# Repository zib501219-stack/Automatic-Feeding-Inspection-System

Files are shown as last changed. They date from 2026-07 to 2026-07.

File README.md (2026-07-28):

# 阶梯轴自动上料与检测设备

本目录为按简历项目重新建立的可编辑机械设计包。关键自制件采用 SolidWorks 原生草图、拉伸、凸台等特征建模；外购电机、减速机、气缸和振动盘为接口级简化件，并在 BOM 中单独标明。

## 简历基线

- 阶梯轴长度 60 mm、最大直径 20 mm
- 振动盘加直线轨道
- V 形块定位
- 气源压力 0.5 MPa

## 工程补全说明

- 阶梯轴按总长 60 mm、最大直径 20 mm 建模；其余台阶尺寸为工艺布置用设计值。
- 气缸按 0.5 MPa 气源选型核算，安装孔和行程为本次设计值。
- 振动盘只保留安装、料斗和出料接口，不宣称具备真实振动整列性能。

## 目录

- `SolidWorks/parts`：原生零件源文件，保留特征树。
- `SolidWorks/assemblies`：功能子装配与总装源文件。
- `STEP`：零件、子装配和总装交换格式。
- `Drawings`：关键零件与总装的 SolidWorks 工程图、PDF、DXF。
- `Screenshots`：零件、子装配和总装等轴测截图。
- `Documents`：参数、BOM、计算说明和制造说明。
- `Validation`：生成记录与打开验证记录。

## 装配状态

- 功能子装配内的零件按已复核设计姿态固定，避免再次拖动造成关节错位。
- 总装以基座/机架模块为固定基准，其余模块通过前视、上视、右视三组基准面配合定位。
- `Validation/assembly_correctness_report.json` 记录零件变换、模块配合和关节/支撑链闭合检查。
- `Validation/assembly_views` 提供正视、右视和等轴测复核图。

## 证据边界

这是数字化结构设计和可打开性验证，不等同于实机制造、装配、节拍、精度或负载试验。文件中不会把外购简化件、估算计算或软件打开检查写成实机结果。

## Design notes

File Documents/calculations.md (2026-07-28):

# 设计计算摘要

## 气缸推力

气源压力按 0.5 MPa。分料气缸采用 20 mm 缸径时，理论推力约为 `0.5×π×20²/4 = 157 N`；按 0.8 综合效率，可用推力约 126 N。推料气缸采用 25 mm 缸径时，理论推力约 245 N，可用推力约 196 N。

## 工件与定位

阶梯轴总长 60 mm、最大直径 20 mm。V 形定位块留有侧向调整槽，检测支架留有高度调整槽；这些尺寸用于覆盖不同台阶位置和传感器工作距离。

计算只证明方案级选型有余量，不等同于振动盘节拍、卡料率、检测精度或气缸寿命实测。

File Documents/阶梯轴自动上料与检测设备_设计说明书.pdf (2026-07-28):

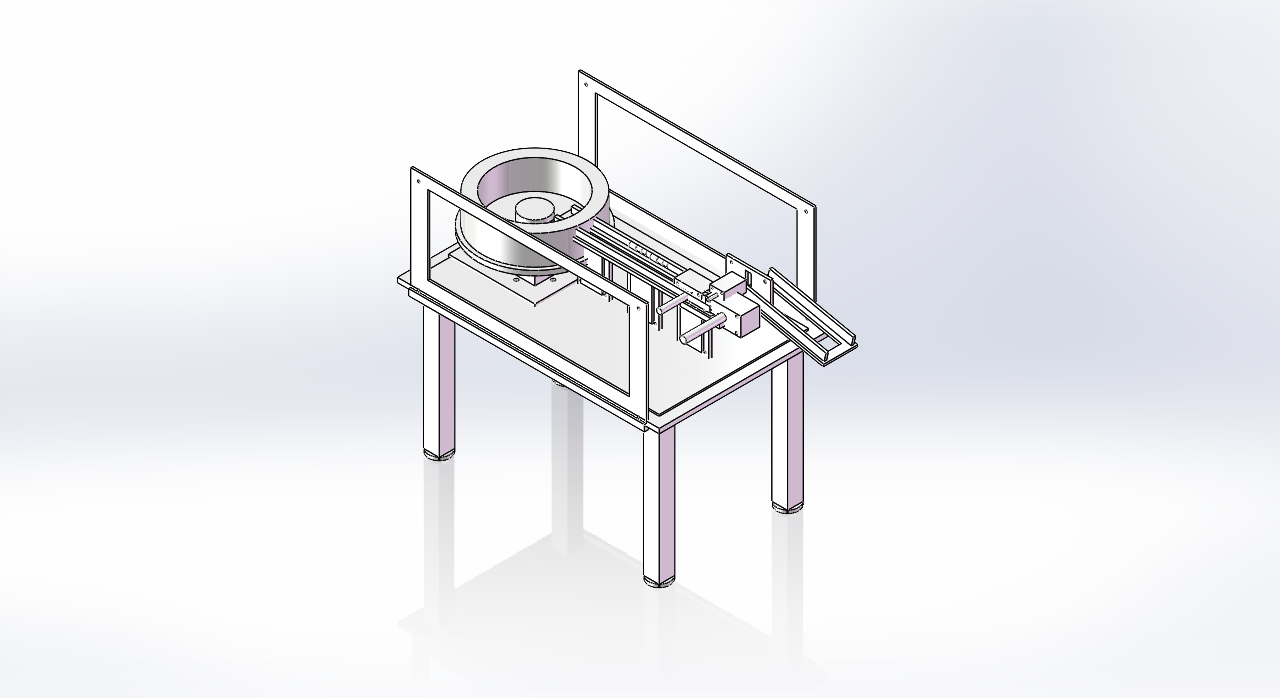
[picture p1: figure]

机械结构设计数字化交付包 | 第 1 页

# 阶梯轴自动上料与检测设备

### 机械结构设计数字化说明书

项目周期 | 2025.10—2026.01
设计软件 | SOLIDWORKS 2023
文件状态 | 原生零件、子装配、总装、STEP、工程图均已生成

说明：本书记录数字化结构设计、工程假设和软件打开检查，不把设计目标、估算或软件仿真写成实机测量结果。

机械结构设计数字化交付包 | 第 2 页

## 1 设计任务与简历基线

本项目按简历中的名称、负载、工作范围、工件规格和功能链重新建立，明确数据直接作为设计输入， 缺失接口尺寸用可追溯工程假设补全。

— 工件长度 60 mm、最大直径 20 mm

— 振动盘与直线轨道

— V 形块定位

— 气源压力 0.5 MPa

### 设计原则

— 关键自制件采用原生草图和特征树，不用导入体冒充源文件。

— 外购电机、减速机、气缸、传感器或振动盘只建接口级简化件。

— 总装按功能模块拆分，保留零件号、子装配和总装层级。

— 制造、装配、实机节拍与负载结果保持边界，不做未验证承诺。

机械结构设计数字化交付包 | 第 3 页

## 2 总体结构方案

### 功能分解

— 机架与台面

— 振动盘与直线送料

— 单件分离与 V 形定位

— 检测、推料与分选防护

总装采用统一项目坐标：SolidWorks 上视基准面建立水平安装面，Y 轴为装配竖直方向。零件定位参数由底座/台面基准逐级展开，功能子装配再插入总装。

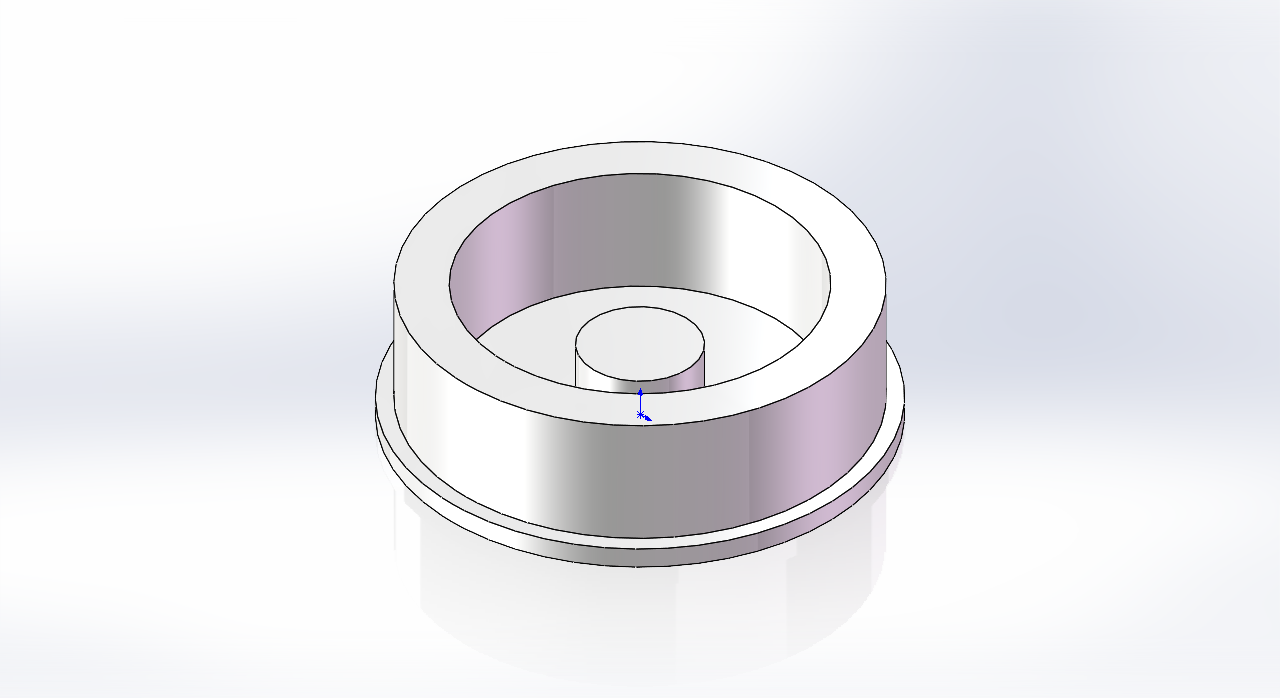
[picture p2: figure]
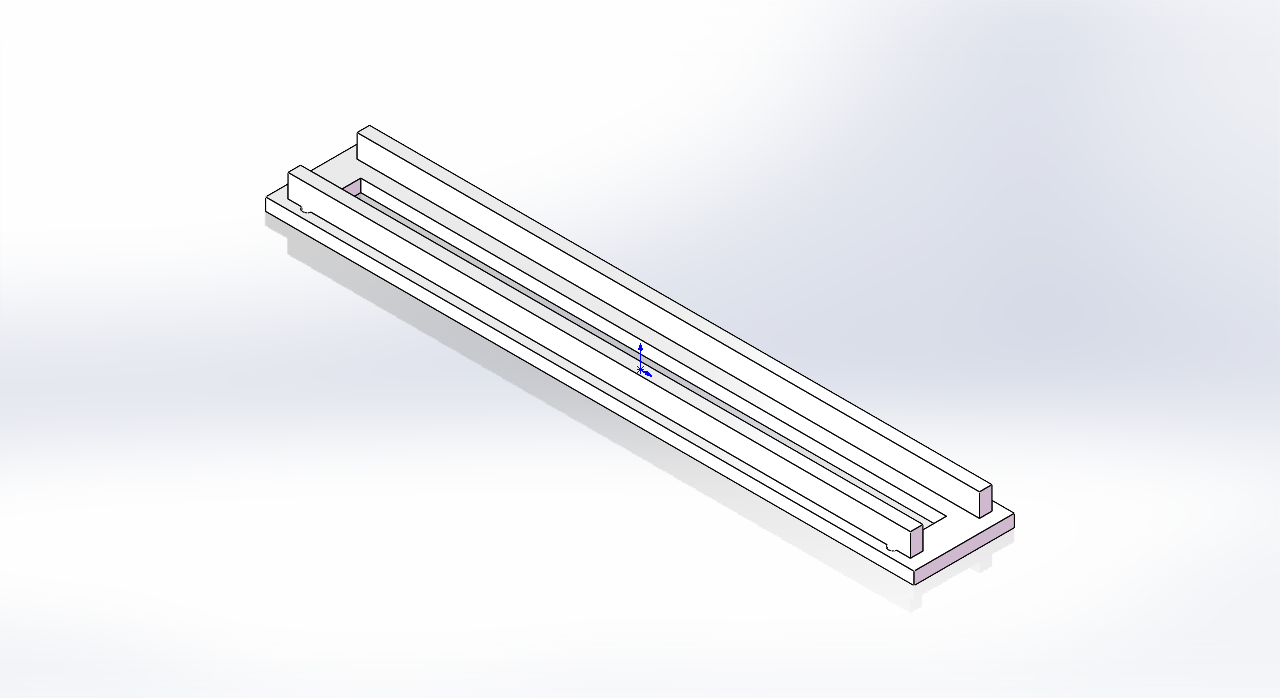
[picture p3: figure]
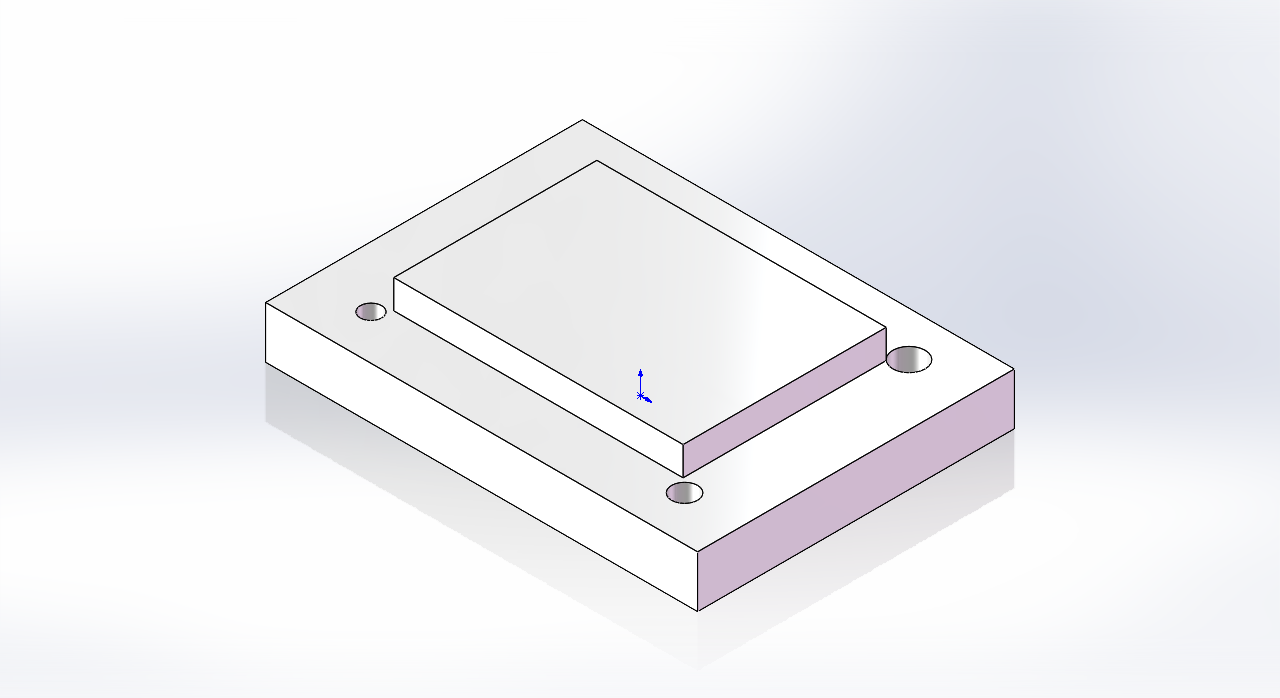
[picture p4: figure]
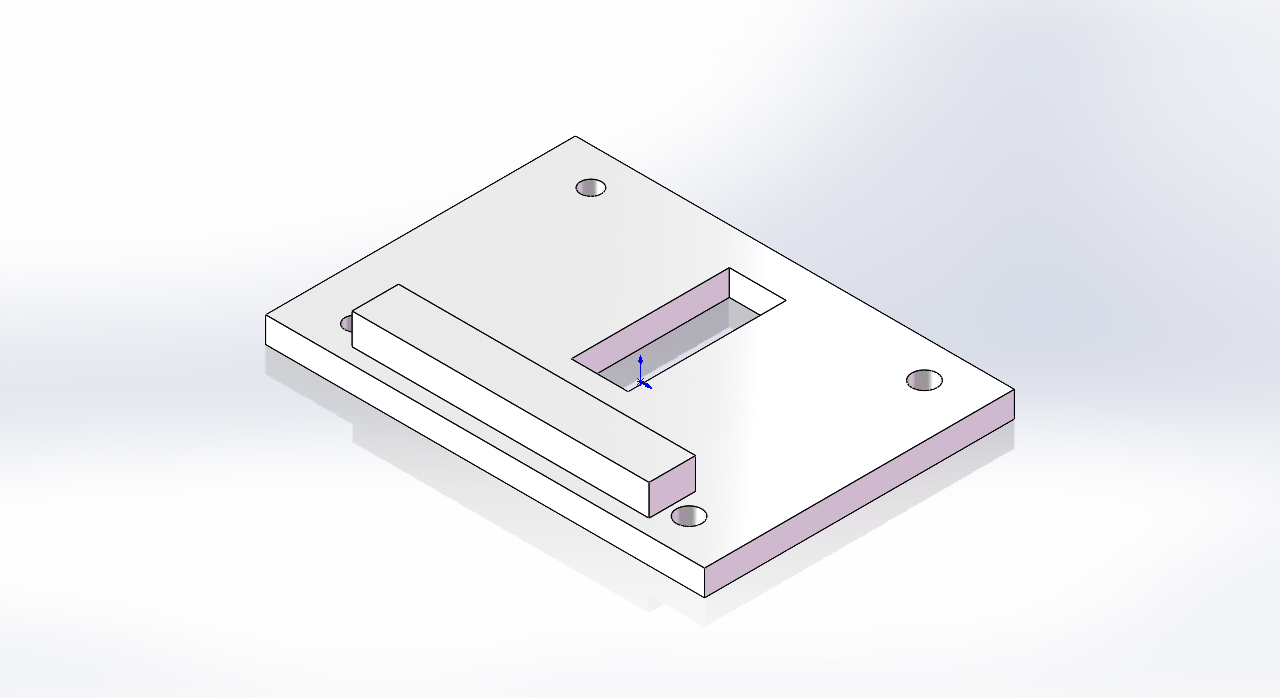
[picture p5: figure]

机械结构设计数字化交付包 | 第 4 页

## 3 关键零件设计

下列零件均保留 SolidWorks 原生特征。板件包含安装孔、调整槽、轴承/定位凸台或加强筋；轴和法兰 采用多级台阶、止口和螺栓圆；外购件以接口包络表达。

机械结构设计数字化交付包 | 第 5 页

## 4 BOM 与零件层级

本项目包含 17 种零件。自制件与外购简化件在 BOM 中分开标识，重复件按实际装配数量统计。

图号 | 名称 | 数量 | 材料/类型 | 建模来源
FD-001 | 设备台面 | 1 | Q235B | 自制件原生建模
FD-002 | 机架立柱 | 4 | Q235B | 自制件原生建模
FD-003 | 振动盘安装板 | 1 | Q235B | 自制件原生建模
FD-004 | 振动盘料斗简化件 | 1 | SUS304 | 外购简化
FD-005 | 振动盘驱动器简化件 | 1 | 外购件 | 外购简化
FD-006 | 直线送料轨道 | 1 | 6061-T6 | 自制件原生建模
FD-007 | 轨道高度调节板 | 3 | Q235B | 自制件原生建模
FD-008 | 单件分离挡块 | 1 | 45钢 | 自制件原生建模
FD-009 | 分料气缸简化件 | 1 | 外购件 | 外购简化
FD-010 | V形定位座底板 | 1 | Q235B | 自制件原生建模
FD-011 | V形定位块 | 2 | 45钢 | 自制件原生建模
FD-012 | 检测传感器支架 | 1 | Q235B | 自制件原生建模
FD-013 | 位移传感器简化件 | 1 | 外购件 | 外购简化
FD-014 | 推料气缸简化件 | 1 | 外购件 | 外购简化
FD-015 | 分选滑槽 | 1 | Q235B | 自制件原生建模
FD-016 | 透明防护罩框架 | 2 | 6061-T6 | 自制件原生建模
FD-017 | 被检测阶梯轴（60×20） | 5 | 45钢 | 自制件原生建模

机械结构设计数字化交付包 | 第 6 页

## 5 选型与校核摘要

— 分料气缸按 20 mm 缸径、0.5 MPa 计算，理论推力约 157 N。

— 按 0.8 综合效率，可用推力约 126 N。

— 推料气缸按 25 mm 缸径计算，理论推力约 245 N，可用推力约 196 N。

— V 形块和检测支架均设置可调安装槽，用于覆盖台阶位置与传感器工作距离。

### 计算边界

上述数值用于结构尺寸和驱动初选。它们没有覆盖真实加减速曲线、摩擦离散、装配误差、温升、寿命 和控制响应，因此不得替代实机试验或厂家选型复核。

机械结构设计数字化交付包 | 第 7 页

## 6 制造与装配考虑

— 板类件优先切割下料，定位孔、轴承孔和止口在基准确定后精加工。

— 轴类件采用车削和台阶精加工；正式出图前补齐配合公差、表面粗糙度和热处理要求。

— 装配按底座/机架、功能臂段/送料模块、末端/检测模块顺序进行，先定位再紧固。

— 所有外购简化件在采购前必须用真实厂家二维图或 STEP 复核孔距、轴径和外形包络。

— 为维护和拆装保留了侧板螺栓空间、调整槽以及模块分界。

### 工程图输出

关键零件和总装均输出 SLDDRW、PDF 和 DXF。PDF 用于浏览，DXF 用于二维交换，正式加工仍应以经审核、补齐公差与技术要求后的版本为准。

机械结构设计数字化交付包 | 第 8 页

## 7 文件与验证记录

项目 | 数量/说明
原生零件 | 17
功能子装配 | 3
总装 | 1
工程图 | 12
交换格式 | STEP / PDF / DXF

— 生成阶段检查原生文件、STEP 和截图均非空。

— 总装 STEP 已进行几何事实、主平面和定位信息检查。

— 总装 STEP 已生成独立 CAD 快照并人工复核结构姿态。

— 交付前还会逐个重开 SLDPRT、SLDASM、SLDDRW、STEP 和 PDF。

— 实机制造、装配、节拍、精度和负载验证不在本次数字化交付范围内。

结论

该设计包能够支撑作品展示、简历项目讲解和后续继续修改。它有清晰的零件号、功能模块、参数来源 和验证边界，可继续补充真实供应商型号、公差、工艺与实机记录。

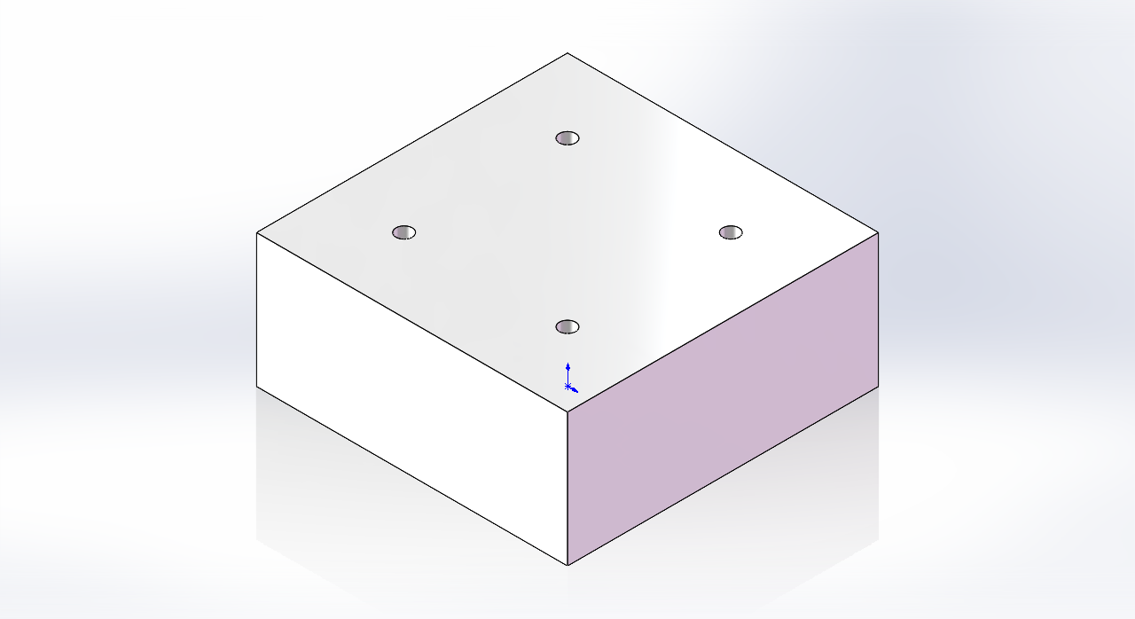
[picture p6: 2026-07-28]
Screenshots/FD-005_bowl_drive.png

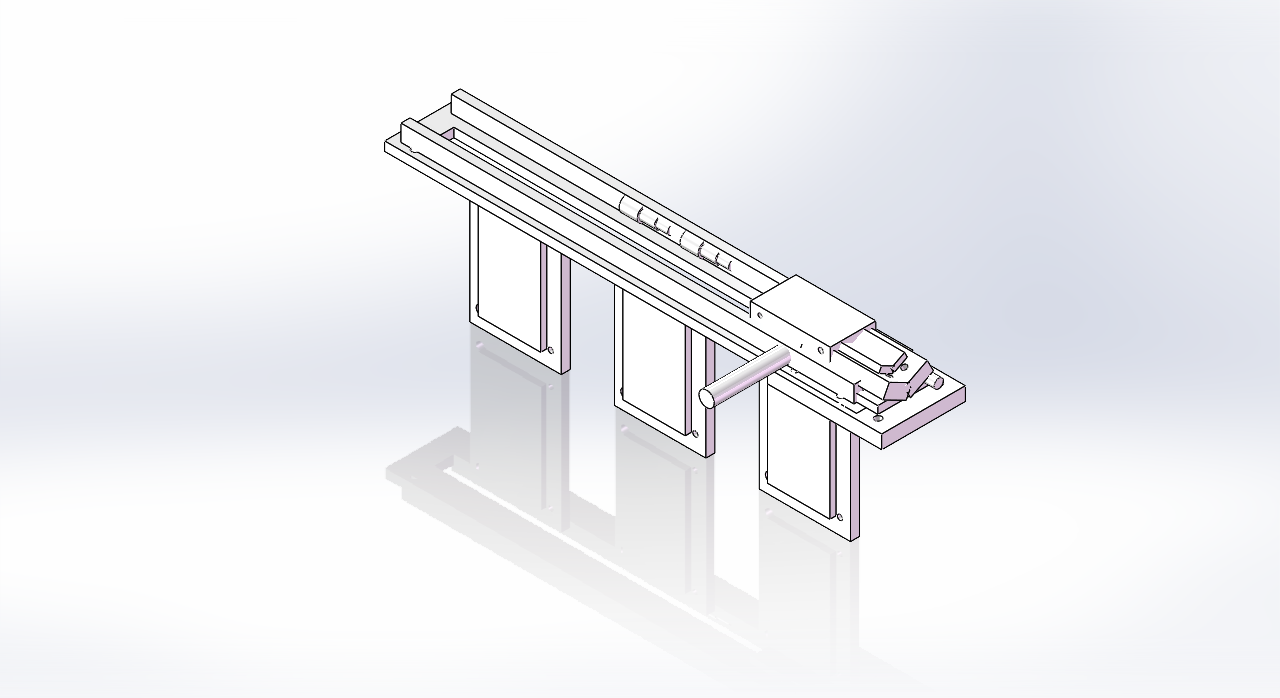
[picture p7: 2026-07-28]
Screenshots/FD-200_feed_position_module.png

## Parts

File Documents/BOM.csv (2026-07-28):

图号 | 名称 | 数量 | 材料/类型 | 建模来源 | 零件文件 | STEP文件
FD-001 | 设备台面 | 1 | Q235B | 自制件原生建模 | FD-001_machine_table.SLDPRT | FD-001_machine_table.STEP
FD-002 | 机架立柱 | 4 | Q235B | 自制件原生建模 | FD-002_frame_leg.SLDPRT | FD-002_frame_leg.STEP
FD-003 | 振动盘安装板 | 1 | Q235B | 自制件原生建模 | FD-003_bowl_base.SLDPRT | FD-003_bowl_base.STEP
FD-004 | 振动盘料斗简化件 | 1 | SUS304 | 外购简化 | FD-004_vibratory_bowl.SLDPRT | FD-004_vibratory_bowl.STEP
FD-005 | 振动盘驱动器简化件 | 1 | 外购件 | 外购简化 | FD-005_bowl_drive.SLDPRT | FD-005_bowl_drive.STEP
FD-006 | 直线送料轨道 | 1 | 6061-T6 | 自制件原生建模 | FD-006_linear_track.SLDPRT | FD-006_linear_track.STEP
FD-007 | 轨道高度调节板 | 3 | Q235B | 自制件原生建模 | FD-007_track_support.SLDPRT | FD-007_track_support.STEP
FD-008 | 单件分离挡块 | 1 | 45钢 | 自制件原生建模 | FD-008_separator_block.SLDPRT | FD-008_separator_block.STEP
FD-009 | 分料气缸简化件 | 1 | 外购件 | 外购简化 | FD-009_separator_cylinder.SLDPRT | FD-009_separator_cylinder.STEP
FD-010 | V形定位座底板 | 1 | Q235B | 自制件原生建模 | FD-010_vblock_base.SLDPRT | FD-010_vblock_base.STEP
FD-011 | V形定位块 | 2 | 45钢 | 自制件原生建模 | FD-011_vblock_jaw.SLDPRT | FD-011_vblock_jaw.STEP
FD-012 | 检测传感器支架 | 1 | Q235B | 自制件原生建模 | FD-012_sensor_bracket.SLDPRT | FD-012_sensor_bracket.STEP
FD-013 | 位移传感器简化件 | 1 | 外购件 | 外购简化 | FD-013_sensor_body.SLDPRT | FD-013_sensor_body.STEP
FD-014 | 推料气缸简化件 | 1 | 外购件 | 外购简化 | FD-014_pusher_cylinder.SLDPRT | FD-014_pusher_cylinder.STEP
FD-015 | 分选滑槽 | 1 | Q235B | 自制件原生建模 | FD-015_diverter_chute.SLDPRT | FD-015_diverter_chute.STEP
FD-016 | 透明防护罩框架 | 2 | 6061-T6 | 自制件原生建模 | FD-016_guard_panel.SLDPRT | FD-016_guard_panel.STEP
FD-017 | 被检测阶梯轴（60×20） | 5 | 45钢 | 自制件原生建模 | FD-017_workpiece_shaft.SLDPRT | FD-017_workpiece_shaft.STEP

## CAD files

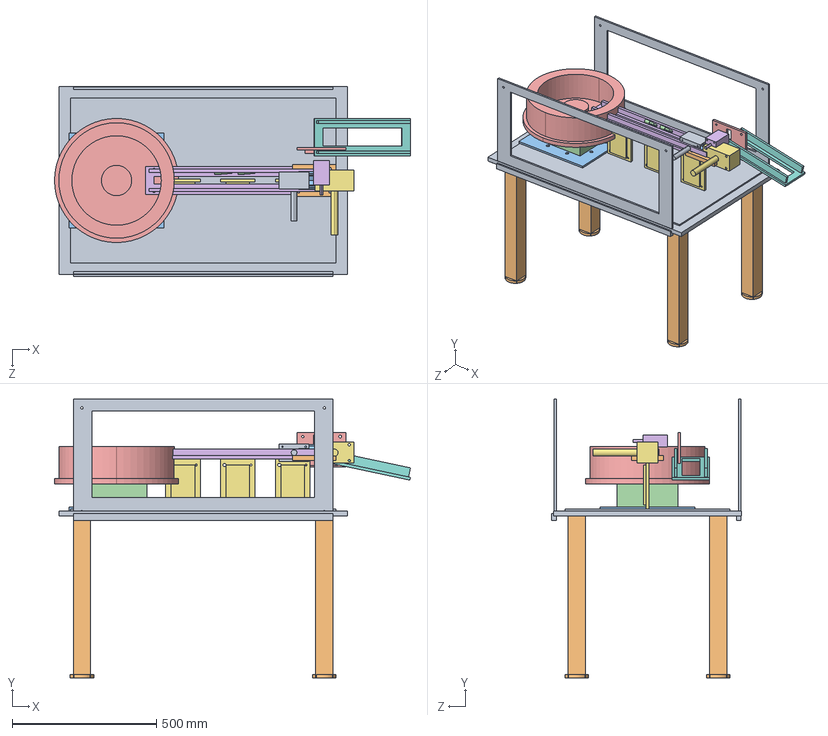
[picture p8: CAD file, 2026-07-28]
STEP/assemblies/FD-000_main_assembly.STEP
1233.4 x 965.0 x 657.0 mm
FD-001_machine_table
FD-002_frame_leg x 4
FD-003_bowl_base
FD-005_bowl_drive
FD-004_vibratory_bowl
FD-006_linear_track
FD-007_track_support x 3
FD-008_separator_block
FD-009_separator_cylinder
FD-010_vblock_base
FD-011_vblock_jaw x 2
FD-017_workpiece_shaft x 3
FD-012_sensor_bracket
FD-013_sensor_body
FD-014_pusher_cylinder
FD-015_diverter_chute
FD-016_guard_panel x 2

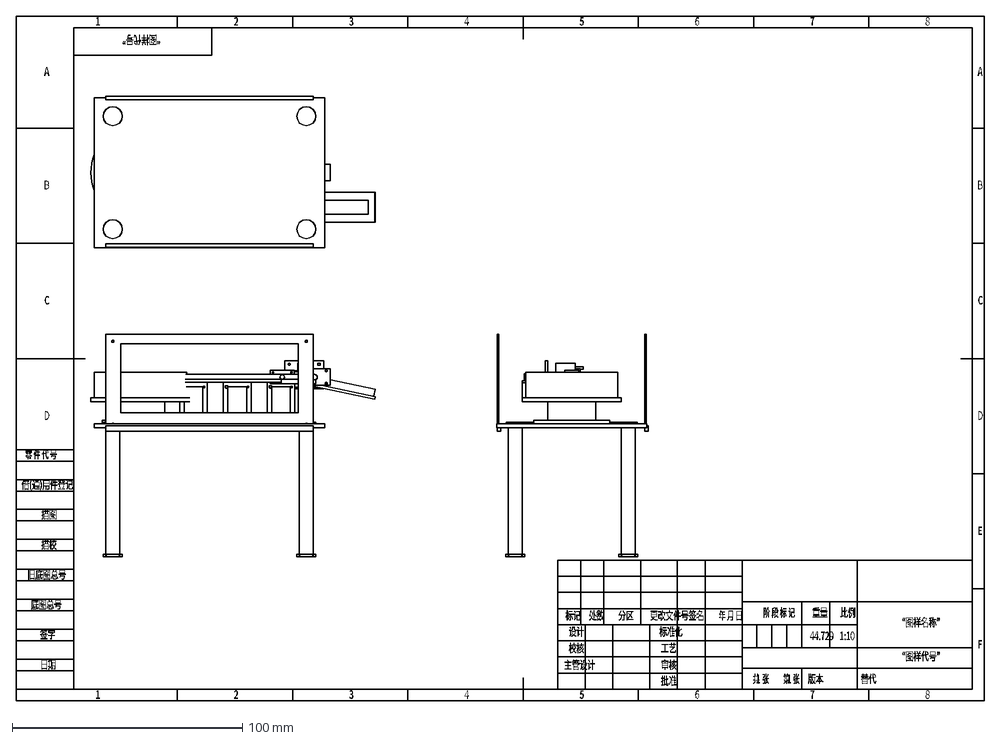
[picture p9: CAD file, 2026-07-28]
Drawings/FD-000_main_assembly.DXF
审核
校核
设计
标记
处数
分区
更改文件号
签名
年 月 日
工艺
标准化
批准
阶 段 标 记
共 张
第 张
重量
比例
日期
签字
底图总号
旧底图总号
描校
描图
借(通)用件登记
零 件 代 号
版本
主管设计
替代
“图样代号”
1:10
1
44.729
“图样名称”
2
7
6
5
4
3
8
F
E
D
C
B
A

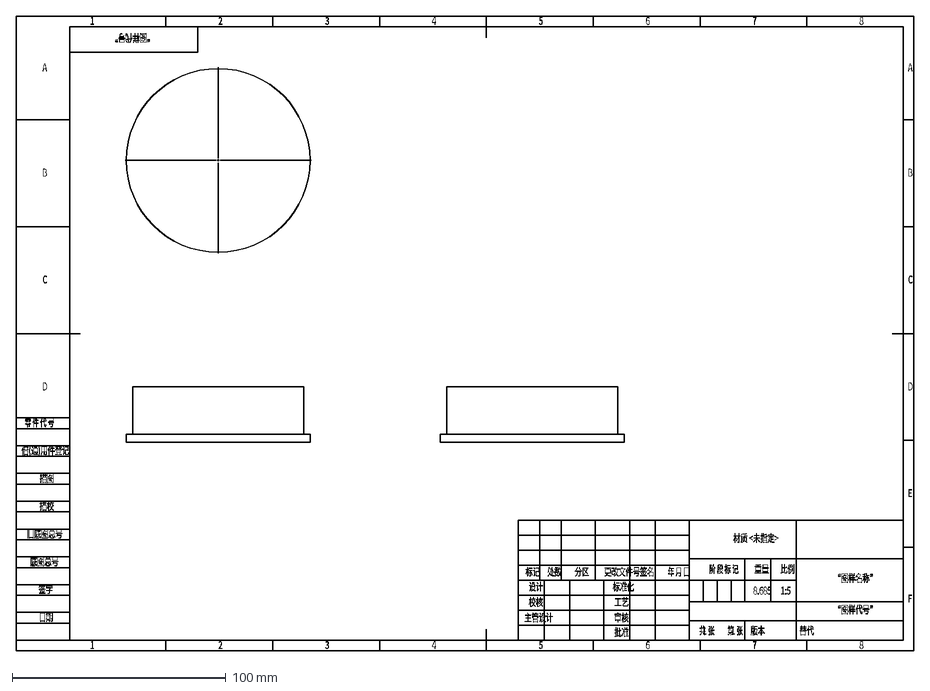
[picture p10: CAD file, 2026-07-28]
Drawings/FD-004_vibratory_bowl.DXF
审核
校核
设计
标记
处数
分区
更改文件号
签名
年 月 日
工艺
标准化
批准
阶 段 标 记
共 张
第 张
重量
比例
日期
签字
底图总号
旧底图总号
描校
描图
借(通)用件登记
零 件 代 号
版本
主管设计
替代
“图样代号”
1:5
1
8.685
“图样名称”
材质 <未指定>
2
7
6
5
4
3
8
F
E
D
C
B
A

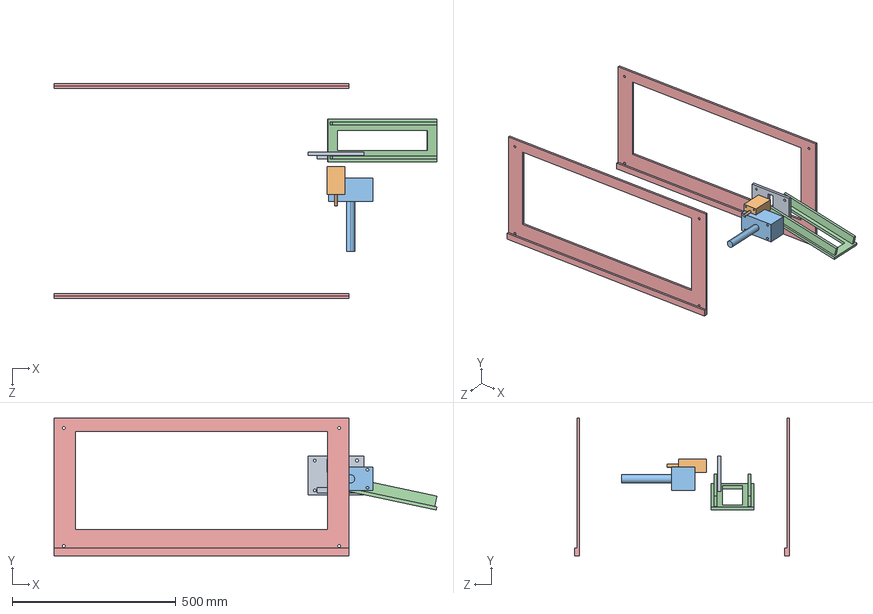
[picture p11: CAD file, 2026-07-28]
STEP/assemblies/FD-300_inspection_divert_module.STEP
1168.4 x 420.0 x 656.0 mm
FD-012_sensor_bracket
FD-013_sensor_body
FD-014_pusher_cylinder
FD-015_diverter_chute
FD-016_guard_panel x 2

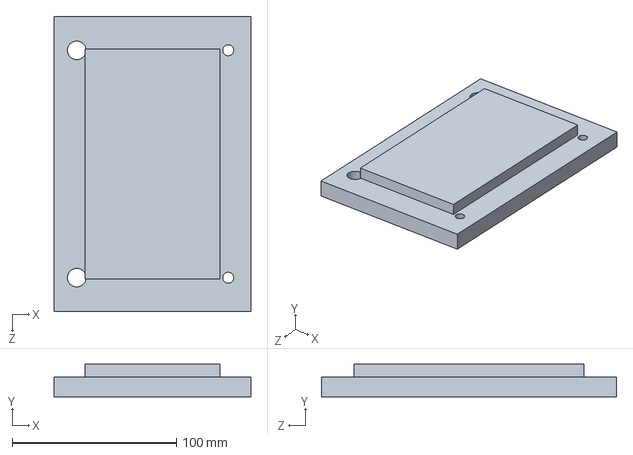
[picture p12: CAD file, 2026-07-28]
STEP/parts/FD-007_track_support.STEP
120.0 x 20.0 x 180.0 mm

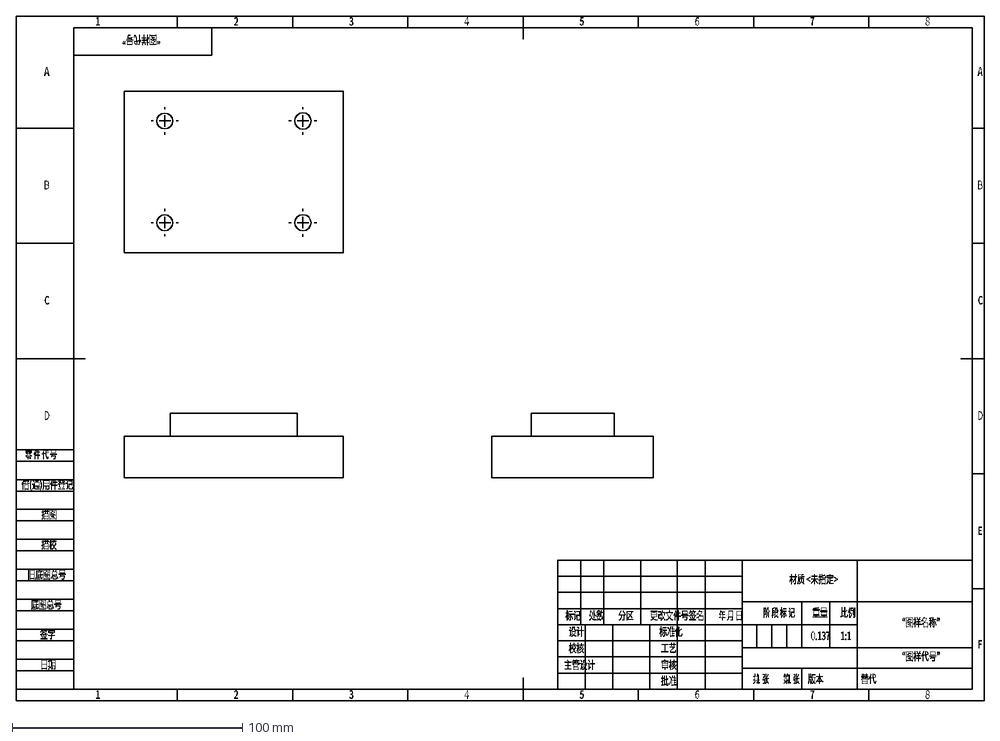
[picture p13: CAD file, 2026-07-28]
Drawings/FD-008_separator_block.DXF
审核
校核
设计
标记
处数
分区
更改文件号
签名
年 月 日
工艺
标准化
批准
阶 段 标 记
共 张
第 张
重量
比例
日期
签字
底图总号
旧底图总号
描校
描图
借(通)用件登记
零 件 代 号
版本
主管设计
替代
“图样代号”
1:1
1
0.137
“图样名称”
材质 <未指定>
2
7
6
5
4
3
8
F
E
D
C
B
A

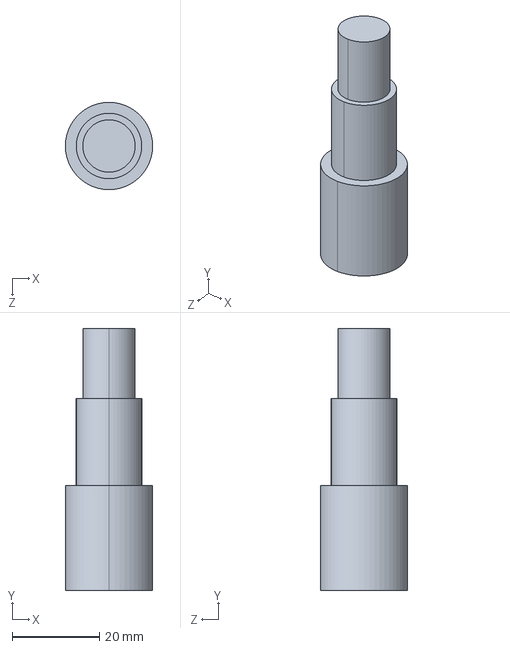
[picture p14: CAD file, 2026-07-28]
STEP/parts/FD-017_workpiece_shaft.STEP
20.0 x 60.0 x 20.0 mm

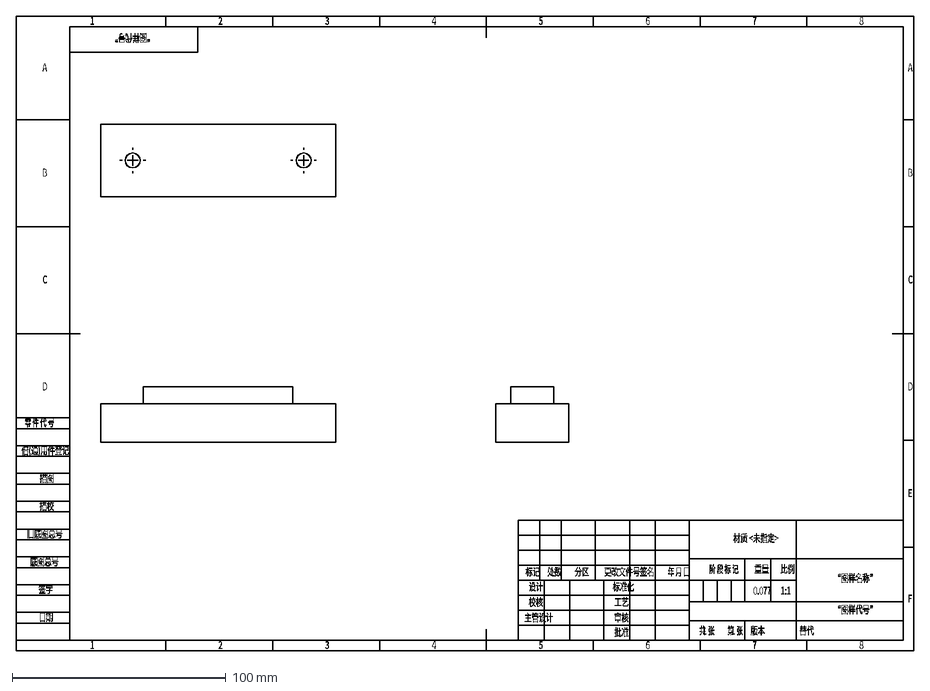
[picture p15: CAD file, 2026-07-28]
Drawings/FD-011_vblock_jaw.DXF
审核
校核
设计
标记
处数
分区
更改文件号
签名
年 月 日
工艺
标准化
批准
阶 段 标 记
共 张
第 张
重量
比例
日期
签字
底图总号
旧底图总号
描校
描图
借(通)用件登记
零 件 代 号
版本
主管设计
替代
“图样代号”
1:1
1
0.077
“图样名称”
材质 <未指定>
2
7
6
5
4
3
8
F
E
D
C
B
A

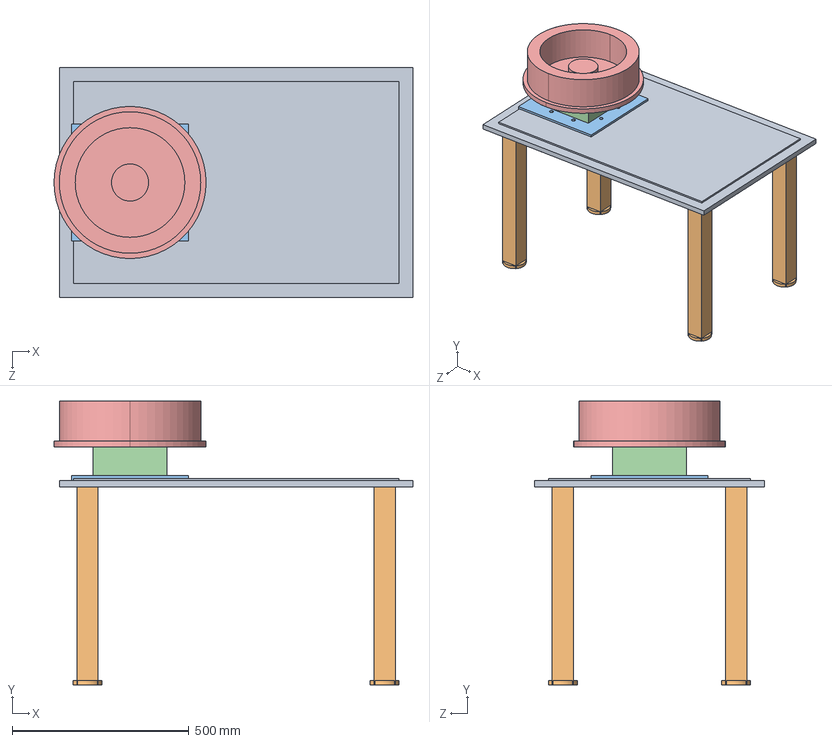
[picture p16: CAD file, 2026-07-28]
STEP/assemblies/FD-100_frame_bowl_module.STEP
1015.0 x 802.0 x 650.0 mm
FD-001_machine_table
FD-002_frame_leg x 4
FD-003_bowl_base
FD-005_bowl_drive
FD-004_vibratory_bowl

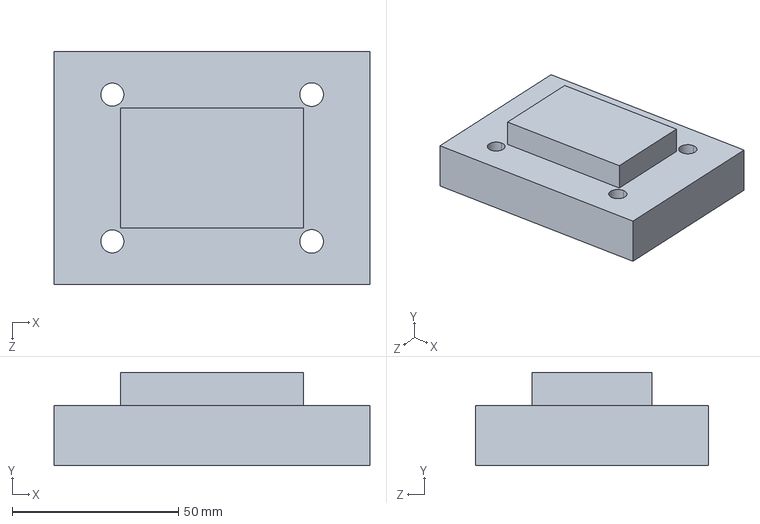
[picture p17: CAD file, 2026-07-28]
STEP/parts/FD-008_separator_block.STEP
95.0 x 28.0 x 70.0 mm

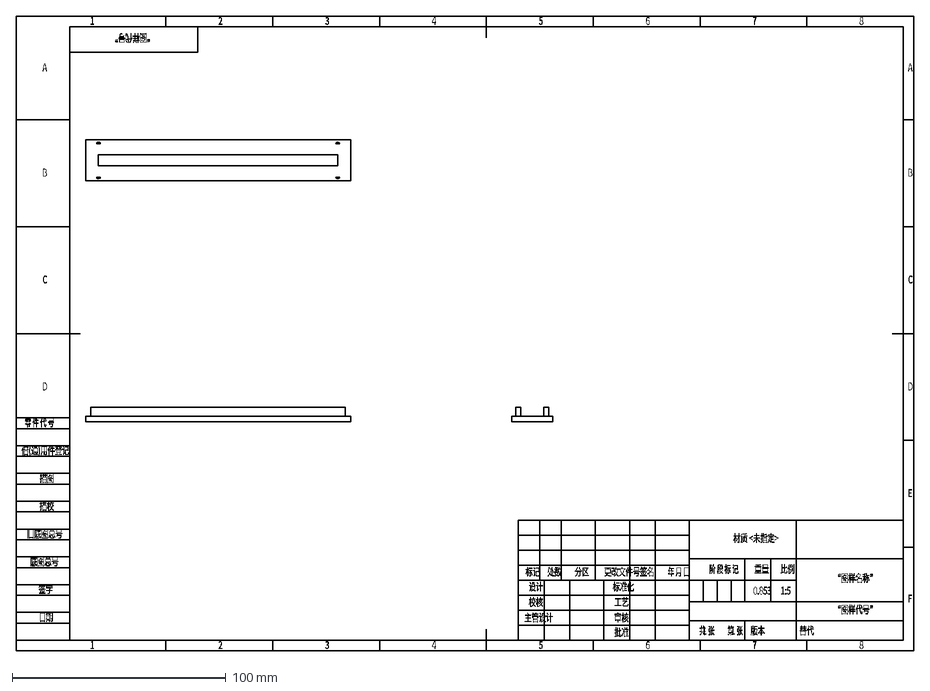
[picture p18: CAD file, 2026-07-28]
Drawings/FD-006_linear_track.DXF
审核
校核
设计
标记
处数
分区
更改文件号
签名
年 月 日
工艺
标准化
批准
阶 段 标 记
共 张
第 张
重量
比例
日期
签字
底图总号
旧底图总号
描校
描图
借(通)用件登记
零 件 代 号
版本
主管设计
替代
“图样代号”
1:5
1
0.853
“图样名称”
材质 <未指定>
2
7
6
5
4
3
8
F
E
D
C
B
A

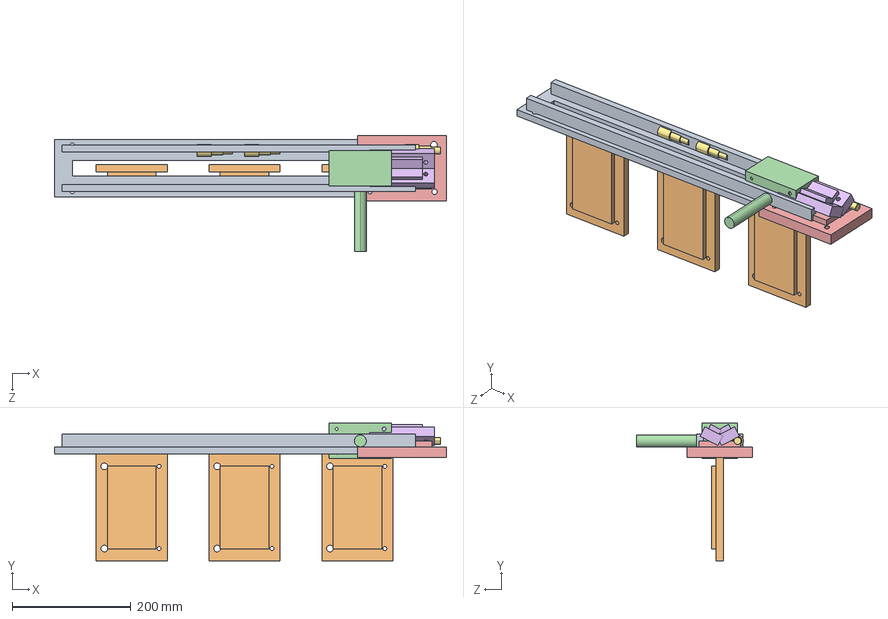
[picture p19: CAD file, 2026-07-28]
STEP/assemblies/FD-200_feed_position_module.STEP
660.0 x 232.0 x 195.0 mm
FD-006_linear_track
FD-007_track_support x 3
FD-008_separator_block
FD-009_separator_cylinder
FD-010_vblock_base
FD-011_vblock_jaw x 2
FD-017_workpiece_shaft x 3

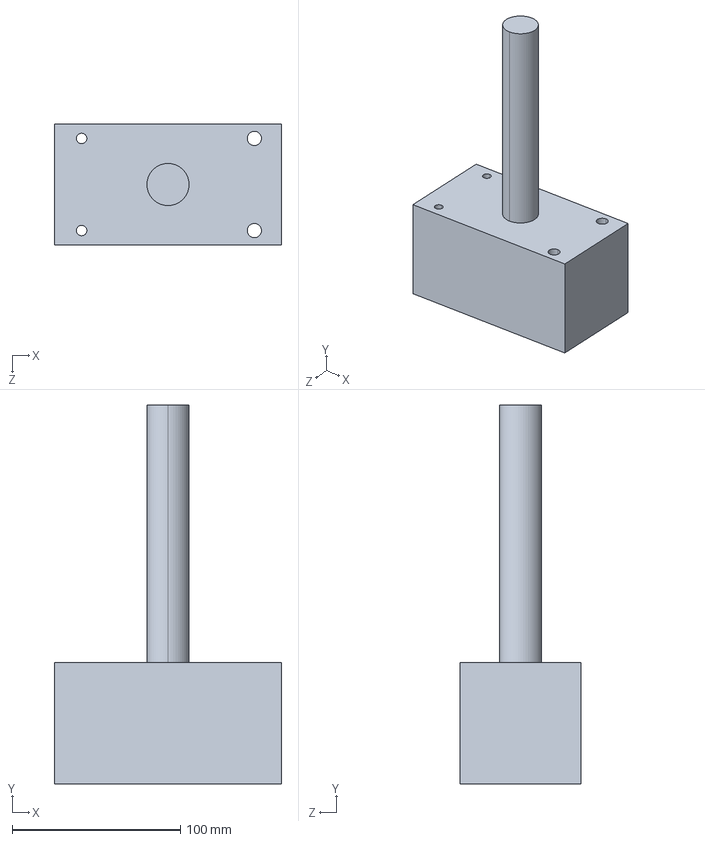
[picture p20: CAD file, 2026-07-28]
STEP/parts/FD-014_pusher_cylinder.STEP
135.0 x 225.0 x 72.0 mm

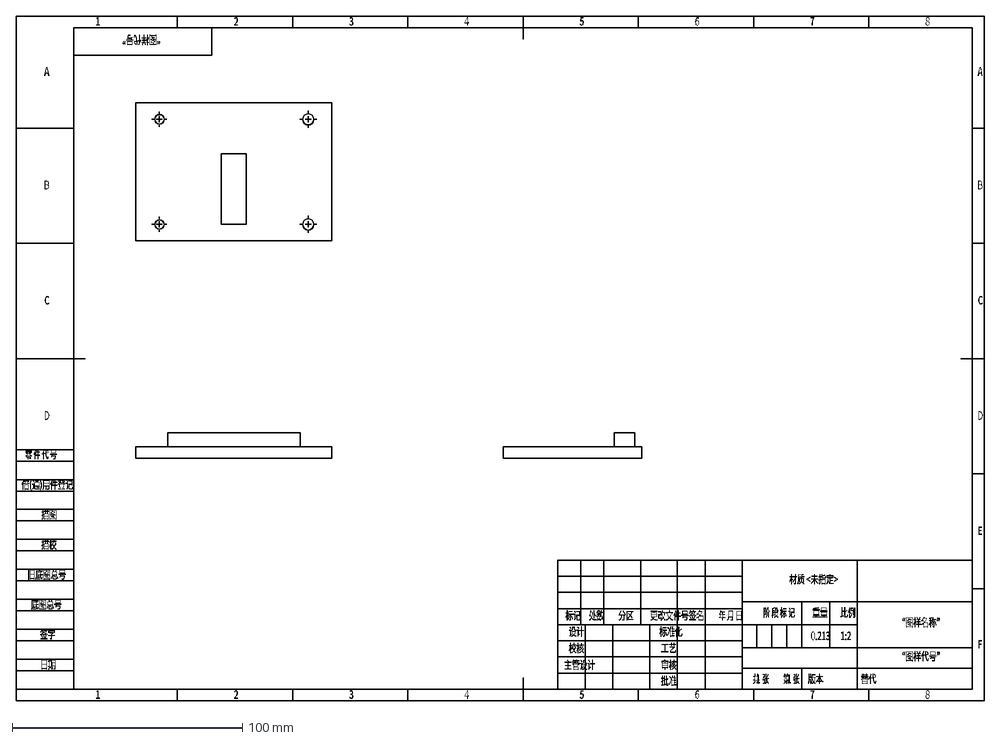
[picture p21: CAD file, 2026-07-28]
Drawings/FD-012_sensor_bracket.DXF
审核
校核
设计
标记
处数
分区
更改文件号
签名
年 月 日
工艺
标准化
批准
阶 段 标 记
共 张
第 张
重量
比例
日期
签字
底图总号
旧底图总号
描校
描图
借(通)用件登记
零 件 代 号
版本
主管设计
替代
“图样代号”
1:2
1
0.213
“图样名称”
材质 <未指定>
2
7
6
5
4
3
8
F
E
D
C
B
A

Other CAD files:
STEP/parts/FD-016_guard_panel.STEP
Drawings/FD-015_diverter_chute.DXF
STEP/parts/FD-013_sensor_body.STEP
Drawings/FD-016_guard_panel.DXF
Drawings/FD-000_main_assembly.SLDDRW
Drawings/FD-001_machine_table.DXF
Drawings/FD-001_machine_table.SLDDRW
Drawings/FD-003_bowl_base.DXF
Drawings/FD-003_bowl_base.SLDDRW
Drawings/FD-004_vibratory_bowl.SLDDRW
Drawings/FD-006_linear_track.SLDDRW
Drawings/FD-008_separator_block.SLDDRW
Drawings/FD-010_vblock_base.DXF
Drawings/FD-010_vblock_base.SLDDRW
Drawings/FD-011_vblock_jaw.SLDDRW
Drawings/FD-012_sensor_bracket.SLDDRW
Drawings/FD-015_diverter_chute.SLDDRW
Drawings/FD-016_guard_panel.SLDDRW
Drawings/FD-017_workpiece_shaft.DXF
Drawings/FD-017_workpiece_shaft.SLDDRW
STEP/parts/FD-001_machine_table.STEP
STEP/parts/FD-002_frame_leg.STEP
STEP/parts/FD-003_bowl_base.STEP
STEP/parts/FD-004_vibratory_bowl.STEP
STEP/parts/FD-005_bowl_drive.STEP
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

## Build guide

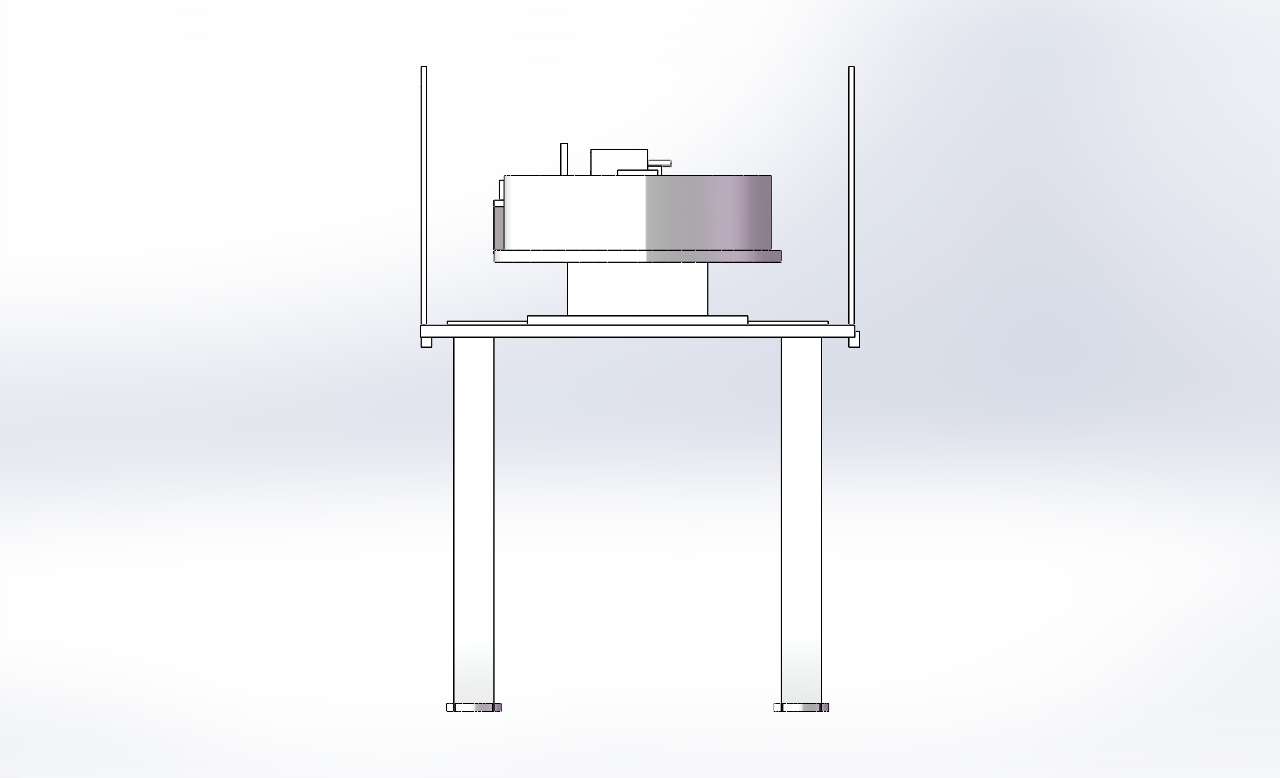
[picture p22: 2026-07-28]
Validation/assembly_views/FD-000_main_assembly_right.png

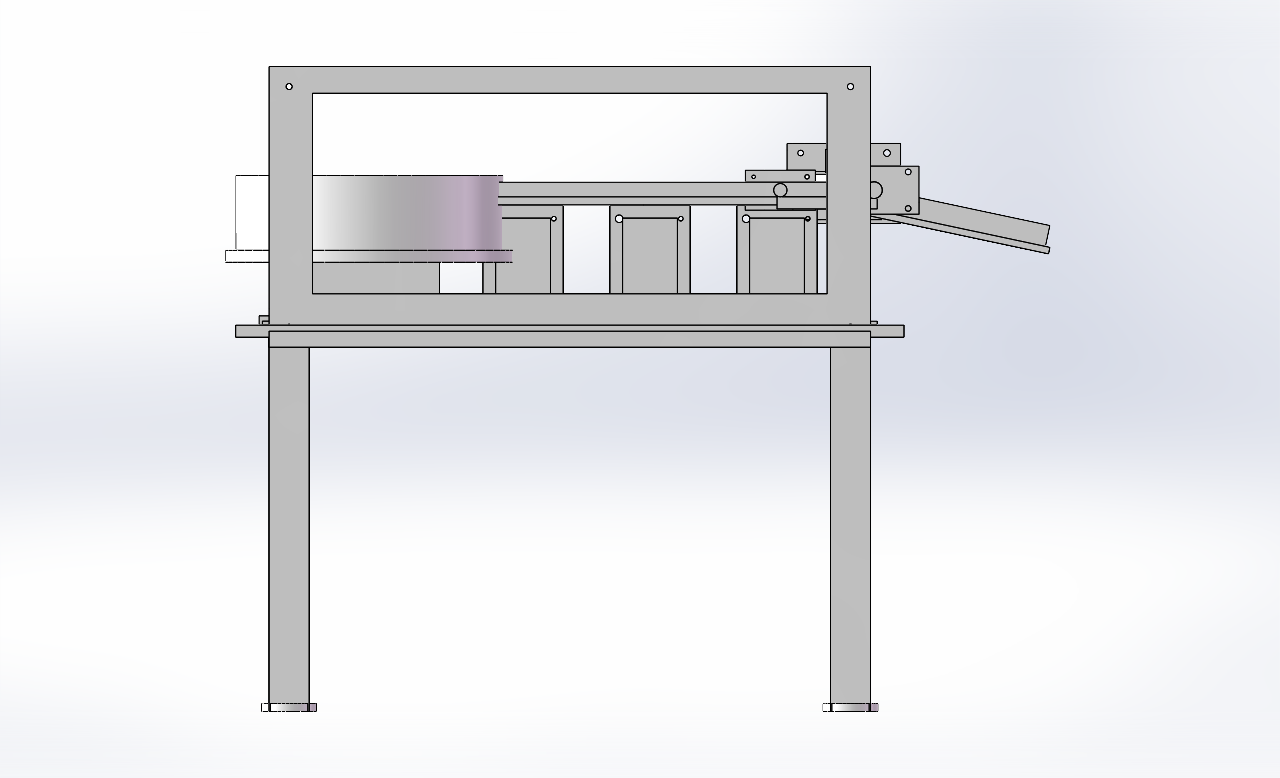
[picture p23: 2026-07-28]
Validation/assembly_views/FD-000_main_assembly_front.png

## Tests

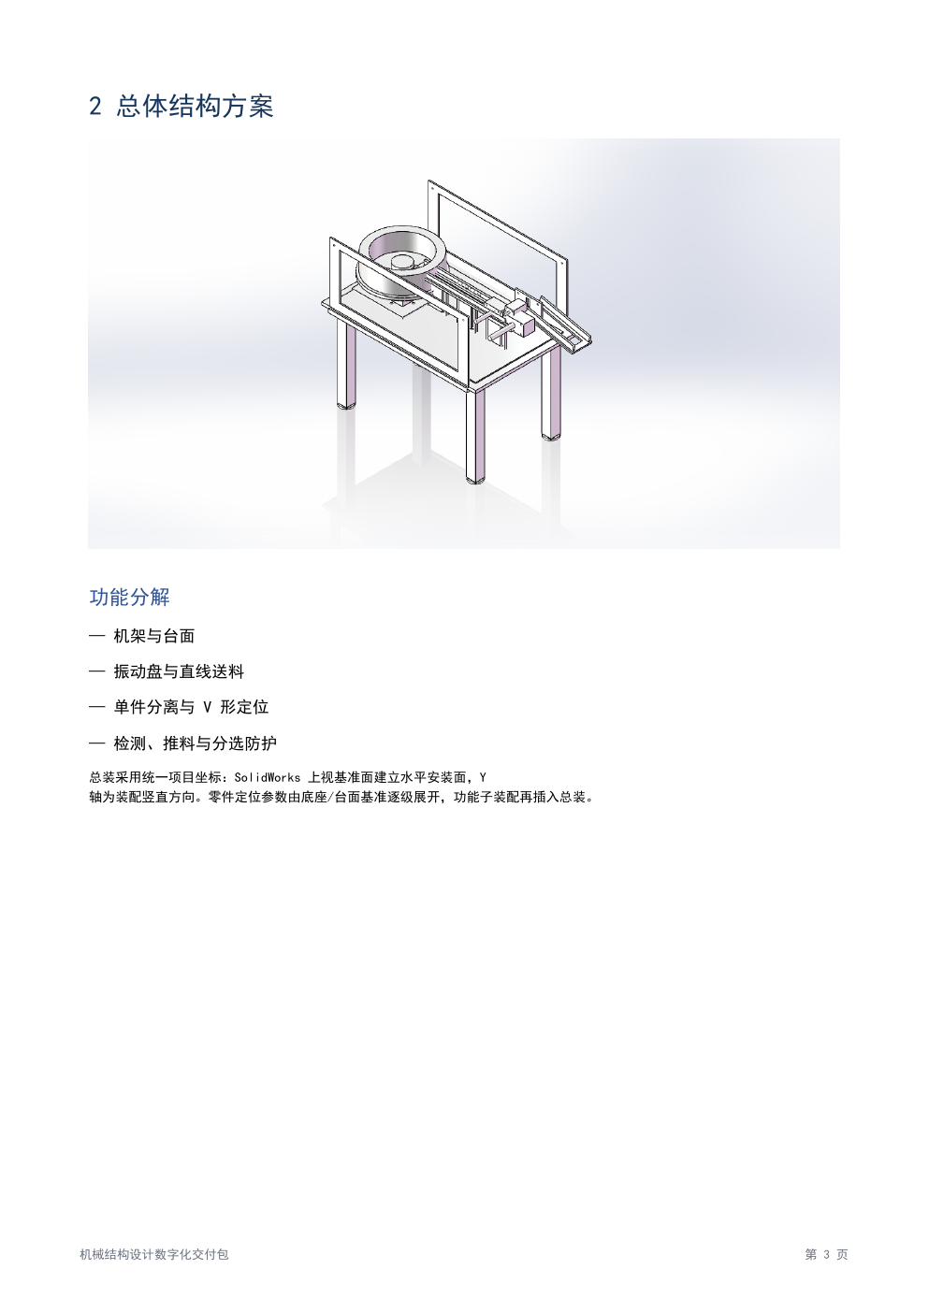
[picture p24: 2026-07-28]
Validation/book_render/page-3.png

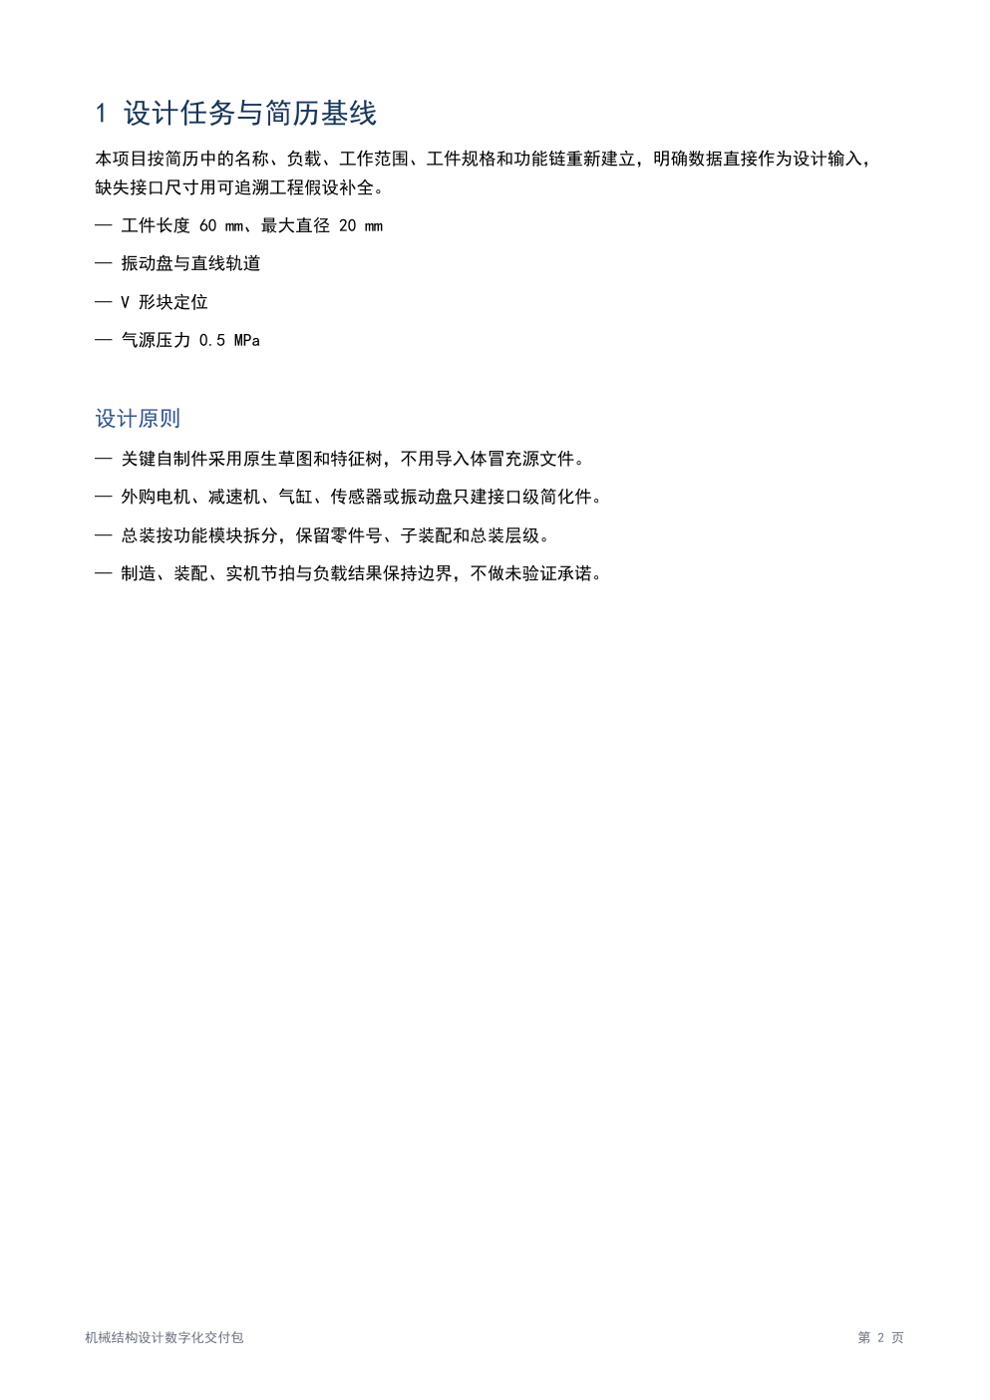
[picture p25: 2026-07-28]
Validation/book_render/page-2.png

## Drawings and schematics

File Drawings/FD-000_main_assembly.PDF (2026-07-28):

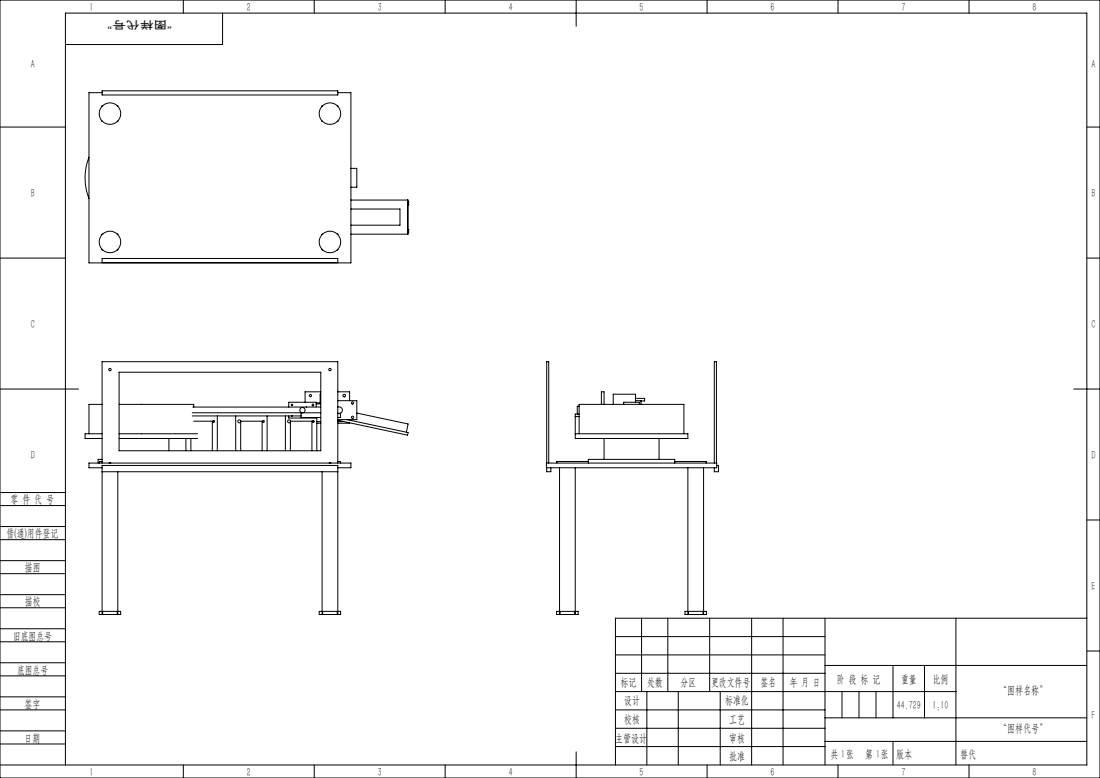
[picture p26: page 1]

阶 段 标 记 | 重量 | 比例 | “图样名称”

标记 | 处数 | 分区 | 更改文件号 | 签名 | 年 月 日
设计 | | | 标准化 | | | | | 44.729 | 1:10
校核 | | | 工艺
主管设计 | | | 审核

“图样代号”

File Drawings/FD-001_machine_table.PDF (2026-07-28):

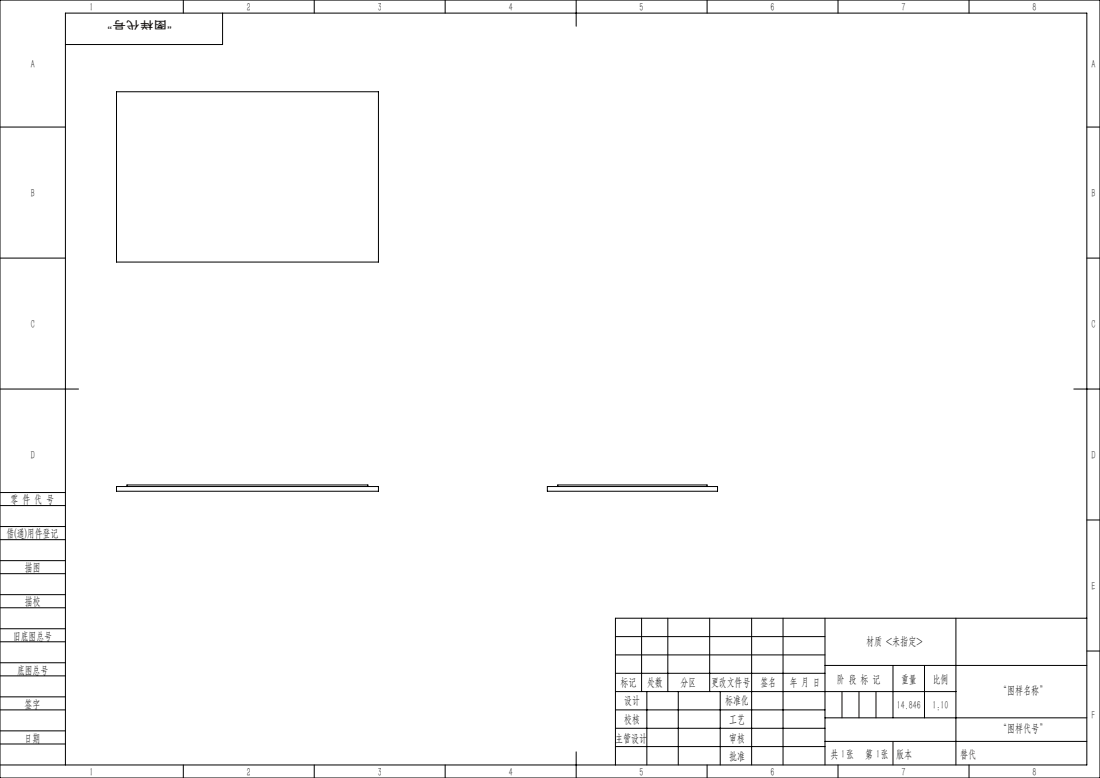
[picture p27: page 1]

材质 <未指定>

阶 段 标 记 | 重量 | 比例 | “图样名称”

标记 | 处数 | 分区 | 更改文件号 | 签名 | 年 月 日
设计 | | | 标准化 | | | | | 14.846 | 1:10
校核 | | | 工艺
主管设计 | | | 审核

“图样代号”

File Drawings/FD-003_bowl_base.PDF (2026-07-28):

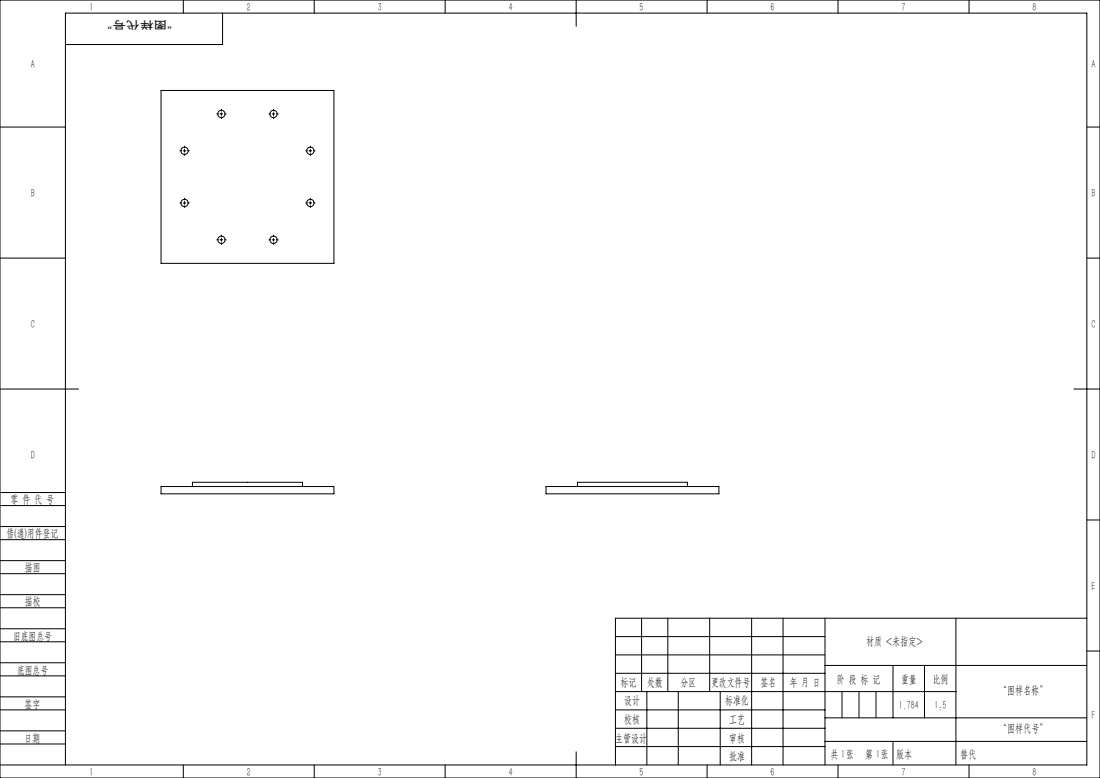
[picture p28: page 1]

材质 <未指定>

阶 段 标 记 | 重量 | 比例 | “图样名称”

标记 | 处数 | 分区 | 更改文件号 | 签名 | 年 月 日
设计 | | | 标准化 | | | | | 1.784 | 1:5
校核 | | | 工艺
主管设计 | | | 审核

“图样代号”

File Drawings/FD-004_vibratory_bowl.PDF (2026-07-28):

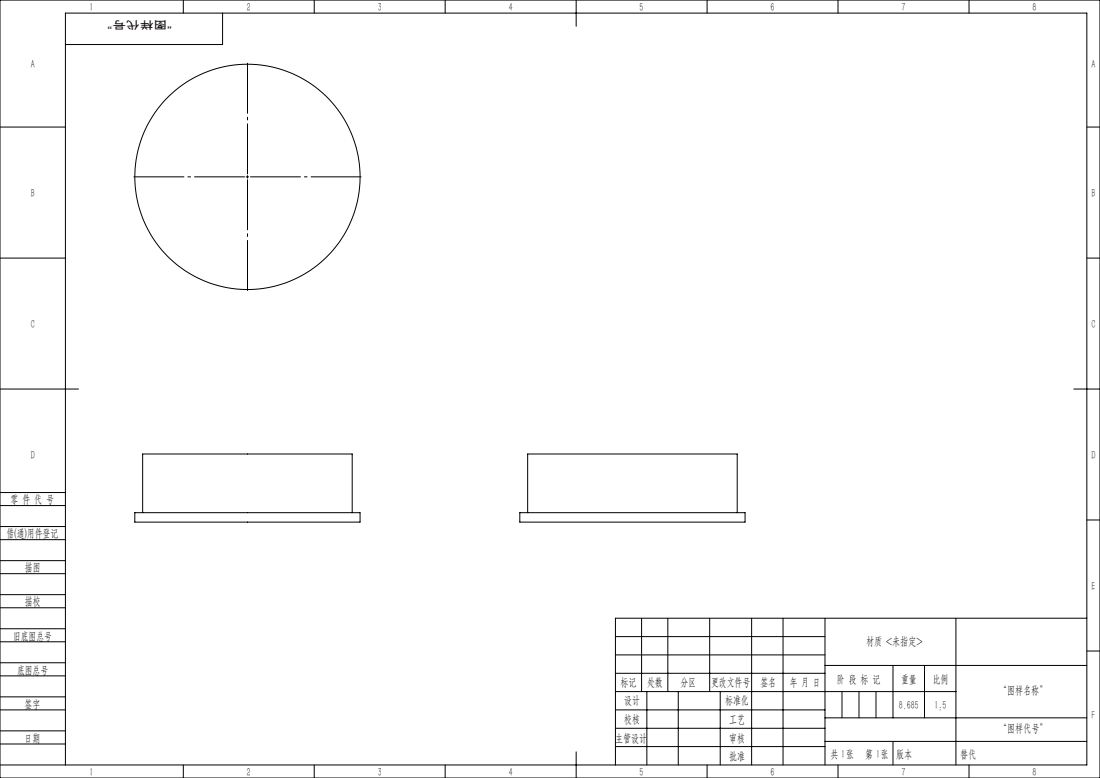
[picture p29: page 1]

材质 <未指定>

阶 段 标 记 | 重量 | 比例 | “图样名称”

标记 | 处数 | 分区 | 更改文件号 | 签名 | 年 月 日
设计 | | | 标准化 | | | | | 8.685 | 1:5
校核 | | | 工艺
主管设计 | | | 审核

“图样代号”

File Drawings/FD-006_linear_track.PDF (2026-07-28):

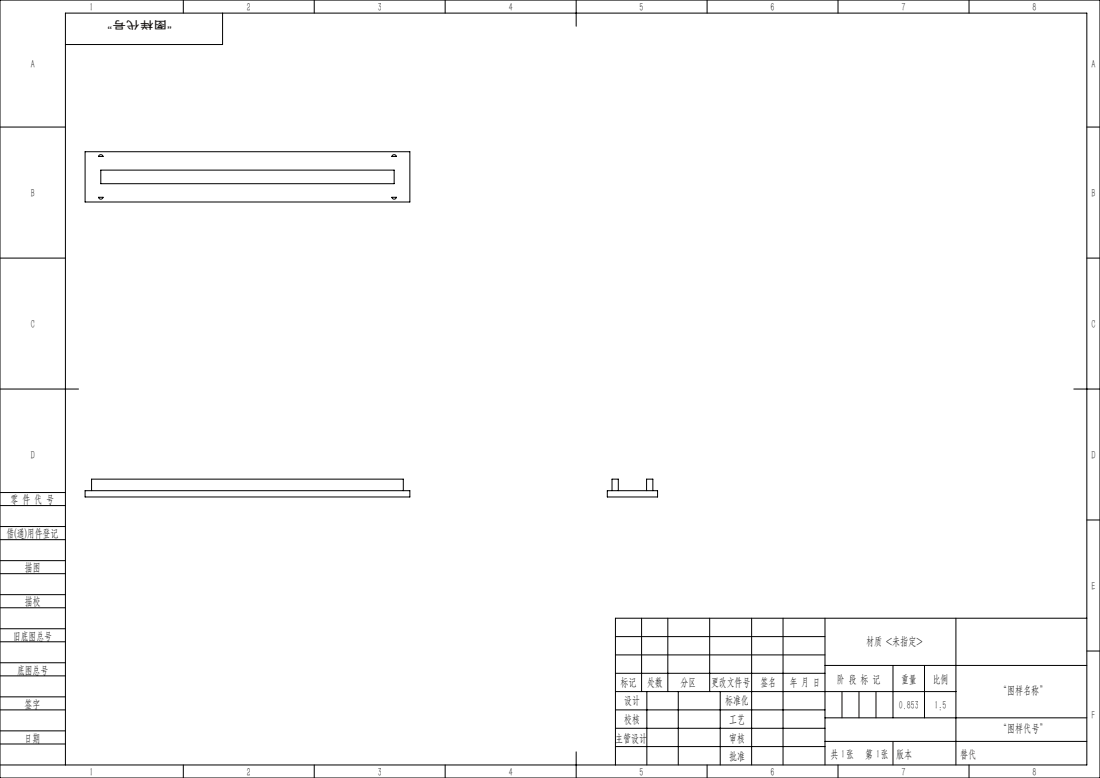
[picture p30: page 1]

材质 <未指定>

阶 段 标 记 | 重量 | 比例 | “图样名称”

标记 | 处数 | 分区 | 更改文件号 | 签名 | 年 月 日
设计 | | | 标准化 | | | | | 0.853 | 1:5
校核 | | | 工艺
主管设计 | | | 审核

“图样代号”

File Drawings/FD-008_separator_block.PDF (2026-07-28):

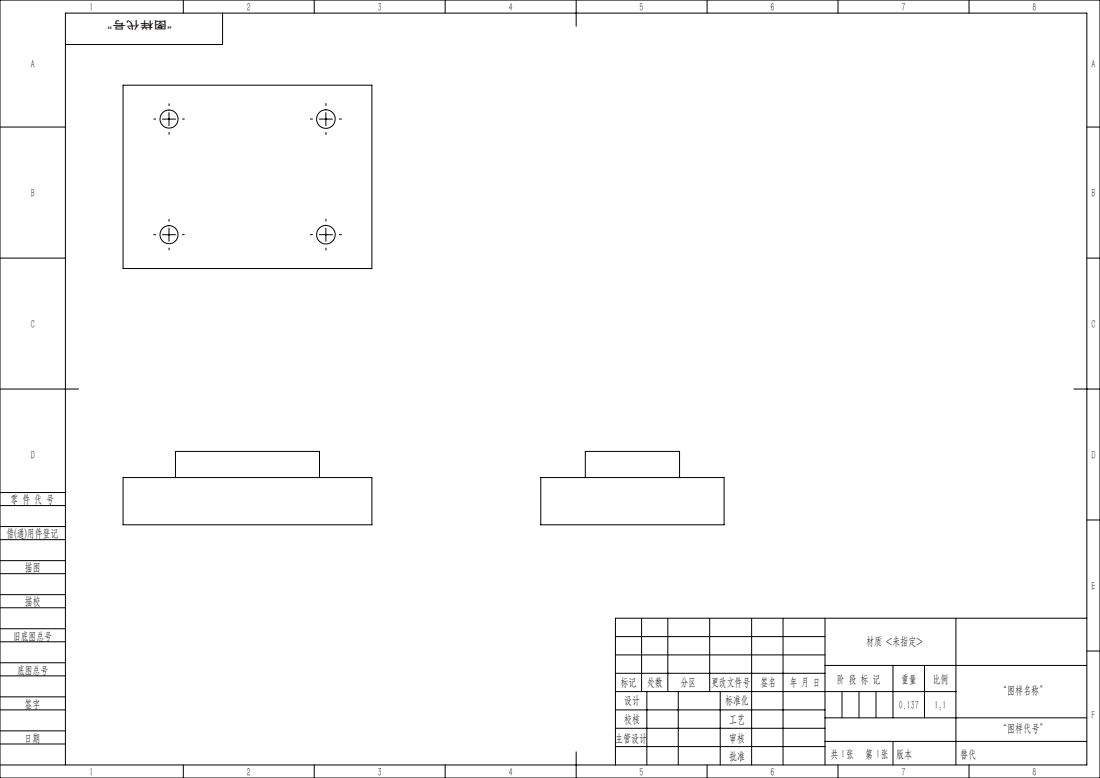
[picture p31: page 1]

材质 <未指定>

阶 段 标 记 | 重量 | 比例 | “图样名称”

标记 | 处数 | 分区 | 更改文件号 | 签名 | 年 月 日
设计 | | | 标准化 | | | | | 0.137 | 1:1
校核 | | | 工艺
主管设计 | | | 审核

“图样代号”

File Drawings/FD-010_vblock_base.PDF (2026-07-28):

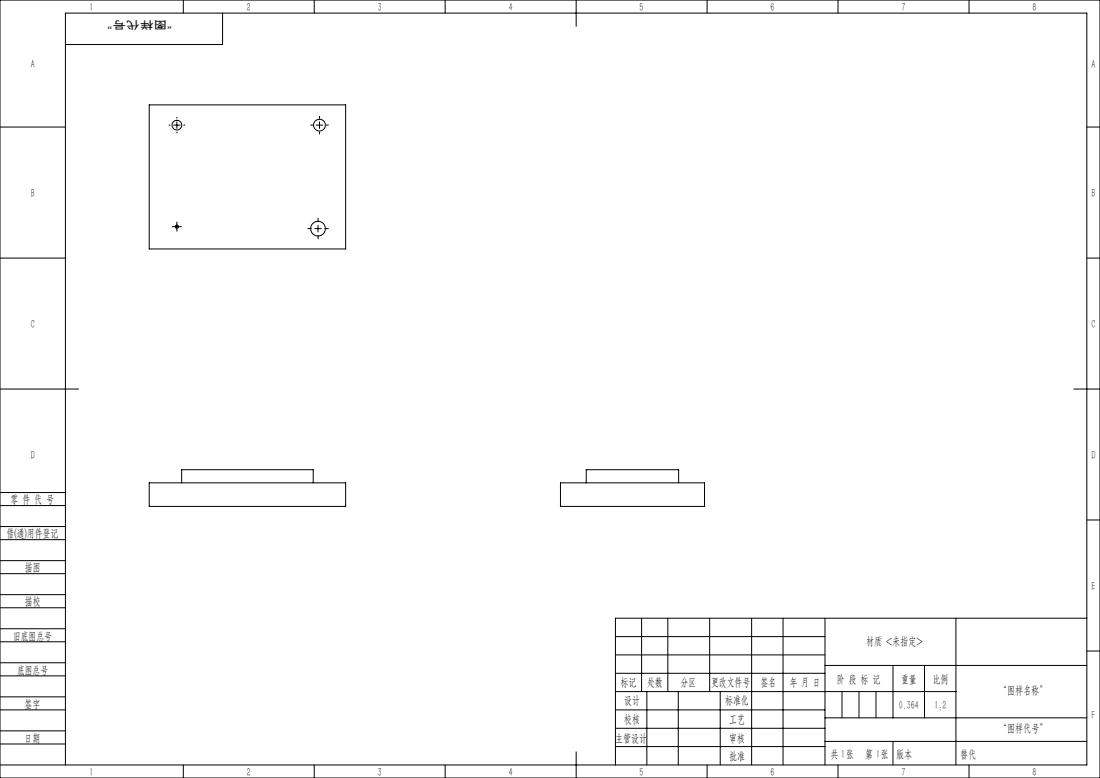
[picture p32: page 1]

材质 <未指定>

阶 段 标 记 | 重量 | 比例 | “图样名称”

标记 | 处数 | 分区 | 更改文件号 | 签名 | 年 月 日
设计 | | | 标准化 | | | | | 0.364 | 1:2
校核 | | | 工艺
主管设计 | | | 审核

“图样代号”

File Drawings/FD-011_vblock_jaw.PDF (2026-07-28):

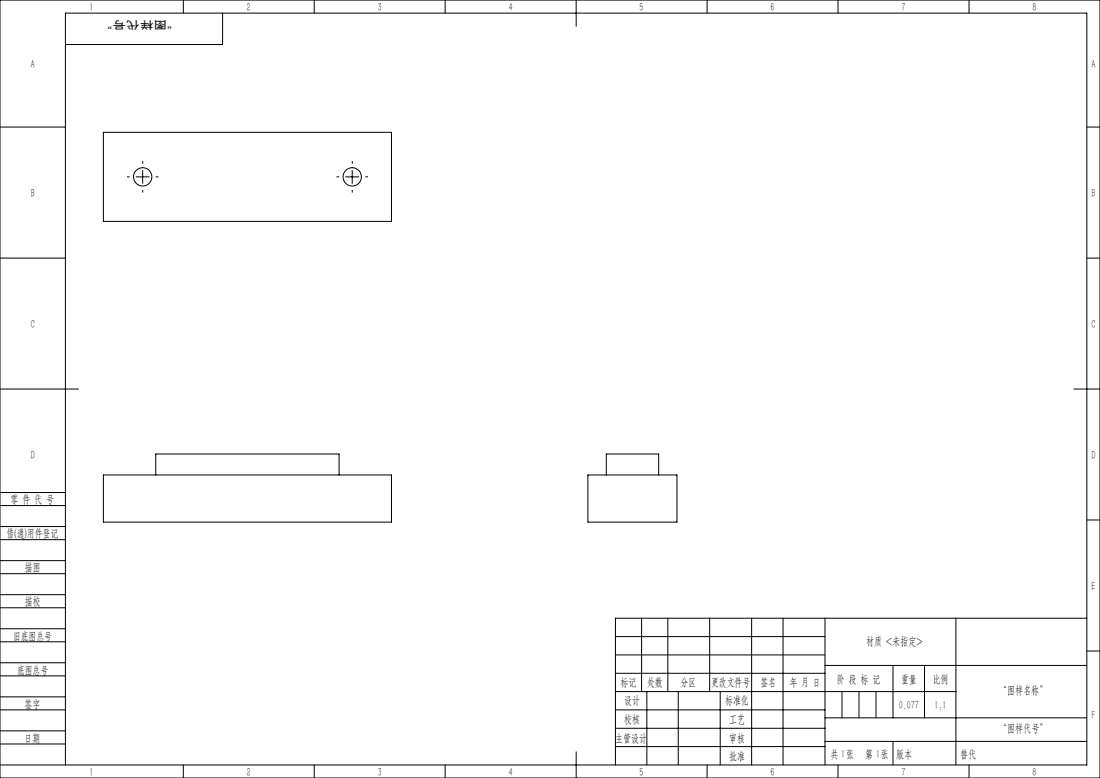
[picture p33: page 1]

材质 <未指定>

阶 段 标 记 | 重量 | 比例 | “图样名称”

标记 | 处数 | 分区 | 更改文件号 | 签名 | 年 月 日
设计 | | | 标准化 | | | | | 0.077 | 1:1
校核 | | | 工艺
主管设计 | | | 审核

“图样代号”

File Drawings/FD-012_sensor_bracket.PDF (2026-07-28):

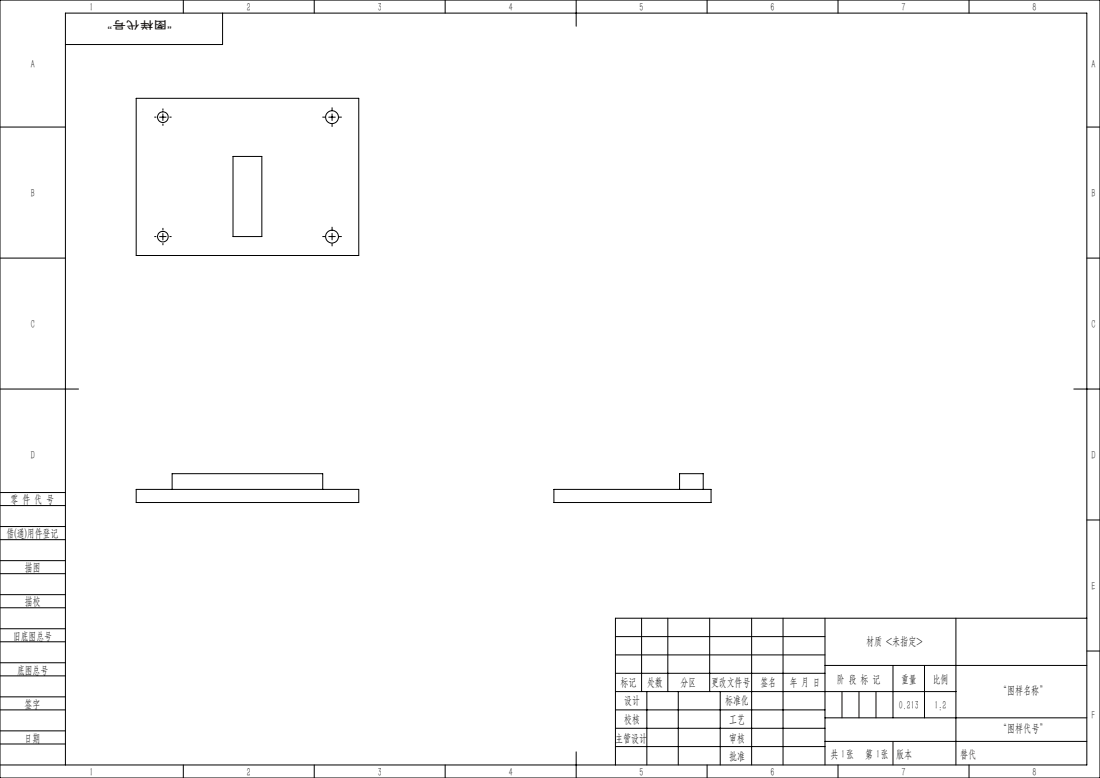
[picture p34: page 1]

材质 <未指定>

阶 段 标 记 | 重量 | 比例 | “图样名称”

标记 | 处数 | 分区 | 更改文件号 | 签名 | 年 月 日
设计 | | | 标准化 | | | | | 0.213 | 1:2
校核 | | | 工艺
主管设计 | | | 审核

“图样代号”

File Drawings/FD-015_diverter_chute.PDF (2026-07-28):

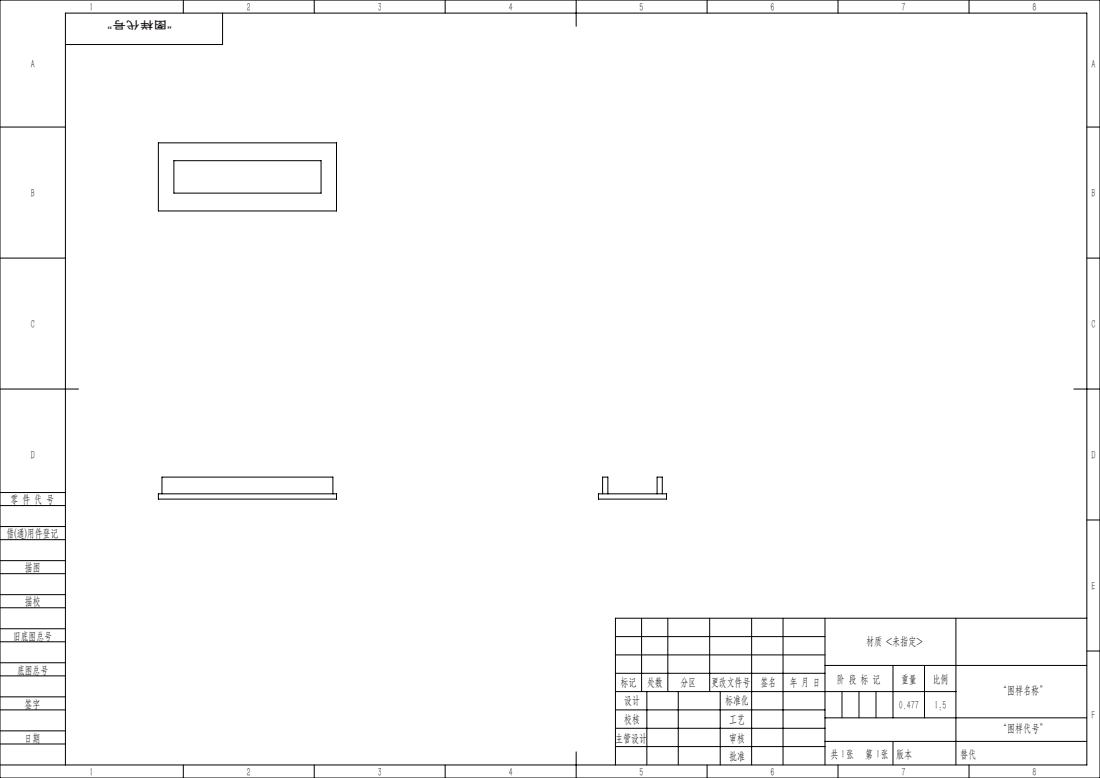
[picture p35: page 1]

材质 <未指定>

阶 段 标 记 | 重量 | 比例 | “图样名称”

标记 | 处数 | 分区 | 更改文件号 | 签名 | 年 月 日
设计 | | | 标准化 | | | | | 0.477 | 1:5
校核 | | | 工艺
主管设计 | | | 审核

“图样代号”

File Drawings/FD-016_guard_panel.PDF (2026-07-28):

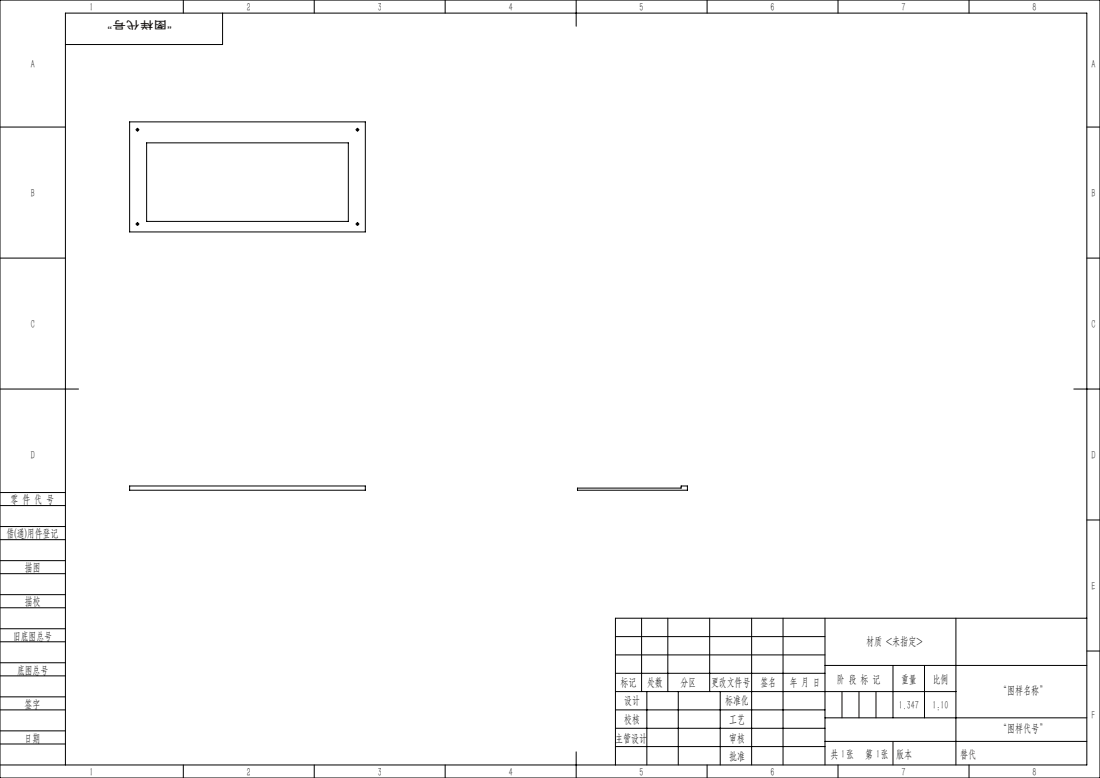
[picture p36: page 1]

材质 <未指定>

阶 段 标 记 | 重量 | 比例 | “图样名称”

标记 | 处数 | 分区 | 更改文件号 | 签名 | 年 月 日
设计 | | | 标准化 | | | | | 1.347 | 1:10
校核 | | | 工艺
主管设计 | | | 审核

“图样代号”

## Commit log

2026-07-15 Complete resume engineering project package
    [BOM.csv, automatic_feeding_inspection.step, io_list.csv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]
2026-07-15 Add bilingual GB-T 2D engineering drawings
    [V形定位座_V_Block_Locator.dxf, 分料安装板_Separator_Mounting_Plate.dxf, 总装图_Overall_Assembly.dxf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]
2026-07-24 Add native SolidWorks key-part source files
    [linear_feeder_track.SLDPRT, linear_feeder_track.STEP, separator_cylinder_mount.SLDPRT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]
2026-07-24 Add enhanced key-part CAD models and reviewed screenshots
    [linear_feeder_track_enhanced.step, separator_cylinder_mount_enhanced.step, transfer_cylinder_bracket_enhanced.step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]
2026-07-24 Add numbered BOM, drawings, and reference assembly package
    [02_feeding_inspection_enhanced_key_parts_reference_assembly.step, BOM_enhanced_key_parts.csv, FI-001_linear_feeder_track.dxf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]
2026-07-24 Add preliminary engineering checks and fit recommendations
    [calculation_inputs.csv, calculation_results.csv, fits_and_tolerances.csv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]
2026-07-24 Add motion envelope and sequence validation
    [cycle_state_samples.csv, cycle_timeline.csv, interlock_matrix.csv]
2026-07-24 Add collision screening structural FE and native format status
    [element_results.csv, nodal_results.csv, overlap_pairs.csv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]
2026-07-24 Close feeder base deflection issue and refresh portfolio
    [02_feeding_inspection_enhanced_key_parts_reference_assembly.step, BOM_enhanced_key_parts.csv, FI-001_linear_feeder_track.dxf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]
2026-07-24 Add second production part batch and verified component mapping
    [BOM_production_parts_v2.csv, FI-005_separator_gate.dxf, FI-005_separator_gate.step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]
2026-07-24 Add PLC design third part batch and procurement freeze
    [BOM_production_parts_v3.csv, FI-005_separator_gate.dxf, FI-007_photo_sensor_bracket.dxf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]
2026-07-28 Complete digital engineering acceptance package
    [acceptance_matrix.csv, controlled_part_drawing_register.csv, p1_digital_closure.csv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]
2026-07-28 Rebuild stepped-shaft feeding inspection portfolio
    [02_feeding_inspection_enhanced_key_parts_reference_assembly.step, BOM.csv, BOM_enhanced_key_parts.csv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]
2026-07-28 Fix assembly geometry and constraints
    [FD-000_main_assembly.DXF, FD-000_main_assembly.SLDASM, FD-000_main_assembly.SLDDRW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]
